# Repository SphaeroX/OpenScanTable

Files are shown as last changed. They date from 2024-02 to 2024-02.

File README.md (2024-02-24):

# OpenScanTable

Welcome to the OpenScanTable project – a modular platform for automated 3D scanning and photography. This project enables users to precisely capture objects from various angles by providing a customizable mount suitable for a wide range of recording devices, including the Revopoint Mini V1 3D scanner and webcams.

## Preview

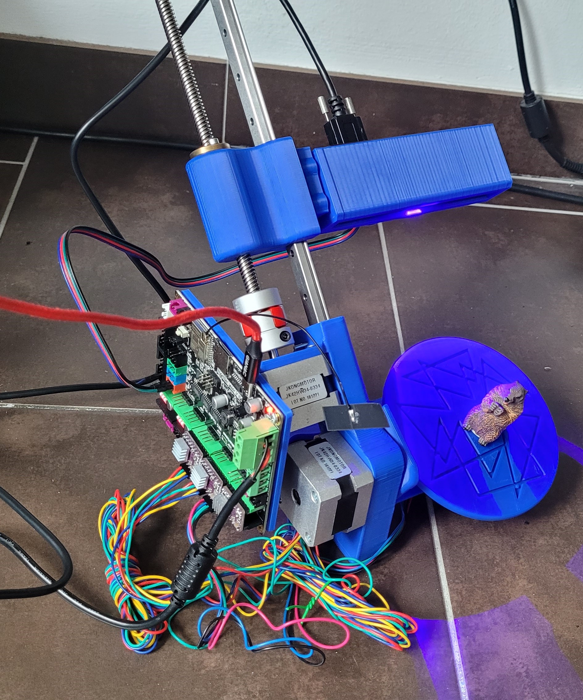
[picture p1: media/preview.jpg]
OpenScanTable in action


[OpenScanTable at YouTube](https://www.youtube.com/shorts/4-4UUVLyI7E "OpenScanTable at YouTube")

## Key Features

- **Modular Design:** Adaptable to different recording devices such as 3D scanners, cameras, and more.
- **Controlled Movements:** Manages the distance, tilt, and rotation of the recording device for optimal results.
- **Automated Scans:** Adjustable scan routines with definable rotation and tilt angles, plus repetitions for complete 360° scans.
- **Bluetooth Control:** Connects to a PC as a Bluetooth device for automated commands, e.g., triggering captures.
- **Web Interface:** Controlled via a user-friendly web interface for easy operation and configuration.
- **3D Printable Components:** All files for 3D printing are available in the hardware folder.

## Technical Details

- **Mainboard:** MKS Tinybee with an ESP32.
- **Programming:** Developed using PlatformIO with the Arduino Library.
- **Automatic Distance Control:** A sensor automatically adjusts the scanner's distance to the object.
- **Versatility:** Suitable for single capture scans with RevoScan or photogrammetry projects with automated image captures.

## Additional Hardware

To assemble OpenScanTable, you will need some additional hardware-
For a complete list of parts and specifications, please refer to the [hardware/BOM.md](./hardware/BOM.md)(Bill of Materials) in this repository.

## Use Cases

- **3D Scanning:** Perfect for detailed 3D models of objects, supported by precise control over capture parameters.
- **Photography:** Ideal for product photography, research and development, where varying perspectives are needed.
- **Photogrammetry:** Enables the creation of 3D models from a series of photographs, including techniques like focus stacking.

## Installation Guide for OpenScanStable

Follow these steps to install and set up your OpenScanStable system. This guide assumes you have a basic understanding of electronics and are familiar with Visual Studio Code and PlatformIO.

First u have to build the hardware (see [hardware/README.md](./hardware/README.md) for more information).

### Pre-requisites

- Visual Studio Code installed on your computer.
- Basic knowledge of using Visual Studio Code and PlatformIO.
- Drivers: https://www.silabs.com/developers/usb-to-uart-bridge-vcp-drivers?tab=downloads
- A MKS TinyBee board or a compatible board.

### Installation Steps

1. **Download and Install PlatformIO Plugin in Visual Studio Code**

   - Open Visual Studio Code.
   - Navigate to the Extensions view by clicking on the square icon on the sidebar or pressing `Ctrl+Shift+X`.
   - Search for "PlatformIO IDE".
   - Click on "Install" to install the PlatformIO IDE extension.

2. **Clone the Repository and Open the Project**

   - Use Git to clone the repository to your local computer. If you're not familiar with Git, you can find numerous guides online to get started.
   - Once cloned, open the folder in Visual Studio Code by selecting `File > Open Folder` and navigating to the cloned project folder.

3. **Prepare and Upload the Firmware to the MKS Tinybee Board**

   - In the PlatformIO sidebar, navigate to the project environment for the MKS Tinybee board.
   - **Build File System Image**
     - First, you need to build the file system image that will be used by the ESP32. This contains the web interface and other necessary files.
     - Find and click on the "Build Filesystem Image" task to compile the image.
   - **Upload File System Image**
     - After building the file system image, upload it to your board by clicking on the "Upload Filesystem Image" task.
   - **Build**
     - Next, compile the main firmware by selecting the "Build" task. This compiles all the source code into a binary file.
   - **Upload**
     - Once the build process is complete, upload the firmware to your MKS Tinybee board by selecting the "Upload" task.

4. **Boot the Mainboard**

   - After uploading the firmware, reboot the MKS Tinybee board to start the newly uploaded software.

5. **Connect Laptop/PC to ESP32 via Bluetooth (For Keyboard Input)**

   - Enable Bluetooth on your laptop or PC.
   - Search for available Bluetooth devices and connect to the ESP32 module named usually as `ESP32 Keyboard`.

6. **Connect to OpenScanStable via WiFi for the Interface**

   - On your computer or a WiFi-enabled device, search for the WiFi network named `OpenScanTable`.
   - Connect to this network using the password provided in your project documentation.
   - Once connected, you can access the web interface by navigating to the IP address specified in the project documentation.

7. **Perform Motor Test and Adjust Drivers**

   - Performing a motor test is essential to confirm that all components are functioning correctly. This step ensures the motors operate as intended for precise control and movement.
   - **Access the Motor Test Feature:** Navigate to the web interface of the OpenScanStable system. Here, you'll find the motor test feature. Follow the on-screen instructions to start the test sequence.
   - **Motor Movement for Distance Measurement:**
     - The motor responsible for moving the measurement device (e.g., sensor) needs to first move upwards before moving downwards. This action ensures that the device can measure the distance accurately and without obstruction.
     - If the motor does not move in the correct order (up then down), you may need to reverse the motor's connection. This adjustment ensures the motor rotates in the correct direction for the intended operation.
   - **Motor Movement for the Rocker:**
     - The motor controlling the rocker (the part that tilts or pivots towards the scanner) should initially rotate towards the scanner. This initial movement is crucial for positioning the object correctly for scanning.
     - If the rocker does not move in the correct direction on the first try, you should reverse the motor's connection. This change will correct the rotation direction, ensuring the rocker moves towards the scanner as intended.
   - **Adjust the Motor Drivers:**
     - During the motor test, carefully adjust the drivers to regulate the amount of current supplied to each motor. The goal is to provide enough current for the motors to operate efficiently without overheating.
     - Supply as much current as necessary for optimal performance but as little as possible to prevent overheating. This balance ensures the longevity and reliability of the motors and drivers.

By following these detailed steps, you can ensure that the motors for the OpenScanStable system are correctly configured and adjusted for optimal performance. This careful setup is crucial for achieving accurate scanning results and maintaining the system's reliability.

## Contributing

The OpenScanTable project thrives on community contribution. We encourage anyone interested to contribute, whether it's through code contributions, creating 3D printing files, or developing new features. Forks and pull requests are warmly welcomed!

## License

This project is open source under an MIT license. For more information, see the LICENSE file.

## Contact

For questions, suggestions, or contributions, please create an issue in the GitHub repository or contact us directly.

We look forward to your contribution and are excited to see what you will create with OpenScanTable!

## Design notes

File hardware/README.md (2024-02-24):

## Pinout

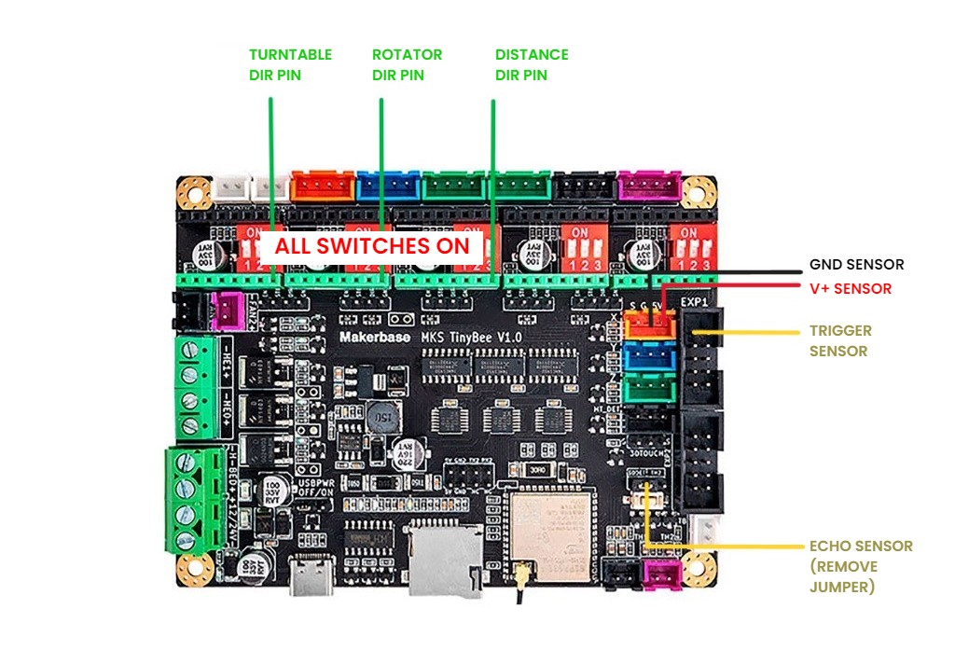
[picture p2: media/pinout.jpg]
Mainboard Pinout


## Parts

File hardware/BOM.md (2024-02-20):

# OpenScanStable - Bill of Materials (BOM)

Below is the Bill of Materials needed to assemble the OpenScanStable project. This list includes 3D-printed parts, electronic components, and other necessary hardware.

## 3D Printed Parts

| Part Name | Quantity | Notes |
| --- | --- | --- |
| Base | 1 | 3D printed |
| Table | 1 | 3D printed |
| Rocker | 1 | 3D printed |
| MGN12_Mount | 1 | 3D printed |
| RP_Mini_Mount | 1 | 3D printed |
| Drive | 1 | 3D printed |
| Mainboard_Mount | 1 | 3D printed |
| Coupler | 1 | 3D printed |

## Electronic Components

| Component | Quantity | Specification |
| --- | --- | --- |
| NEMA 17 Motor | 1 | 42x20mm |
| NEMA 17 Motors | 2 | 42x34mm |
| MKS TinyBee Board | 1 | - |
| Motor Driver (e.g., DRV8825) | 3 | - |
| 24V Power Supply | 1 | 4A |
| VL53L0X Sensor | 1 | - |
| Sensor Cables | - | Preferably with Dupont Connectors |

## Mechanical Components

| Component | Quantity | Specification |
| --- | --- | --- |
| MGN12H Linear Rail | 1 | 250mm Length |
| TR8x8 Lead Screw with T8 Brass Nut | 1 | min 250mm, Acme Thread, 2mm Pitch |
| M3 Screws (20x12mm) | 20 | - |
| M3 Screws (8x10mm) | 10 | - |

Please make sure to source high-quality components to ensure the stability and reliability of your OpenScanStable build. This BOM is provided as a guideline and may be adjusted based on availability or project updates.

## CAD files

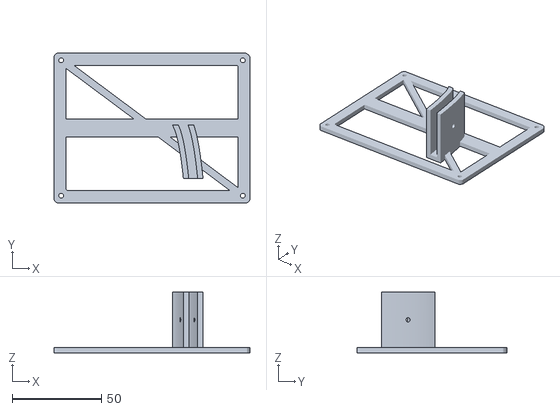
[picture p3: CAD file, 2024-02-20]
hardware/stl/Mainboard_Mount.stl
110.0 x 84.0 x 34.0

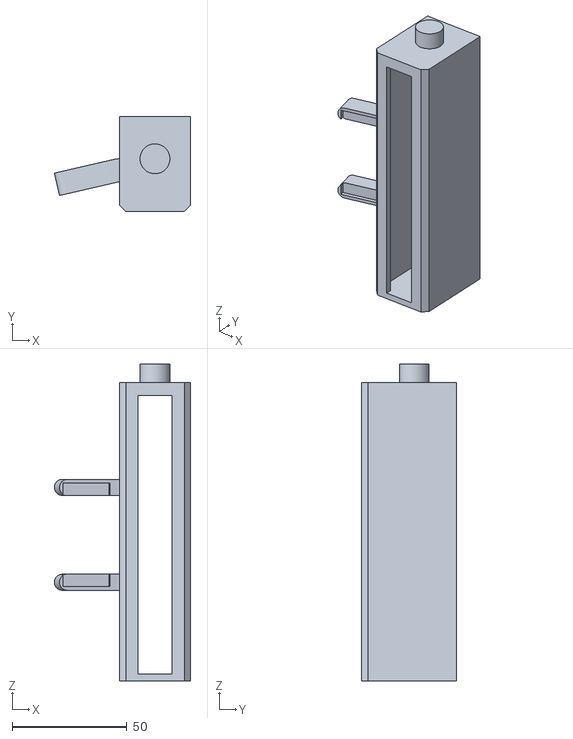
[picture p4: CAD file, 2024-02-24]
hardware/stl/RP_Mini_Mount.stl
59.4 x 41.3 x 138.0

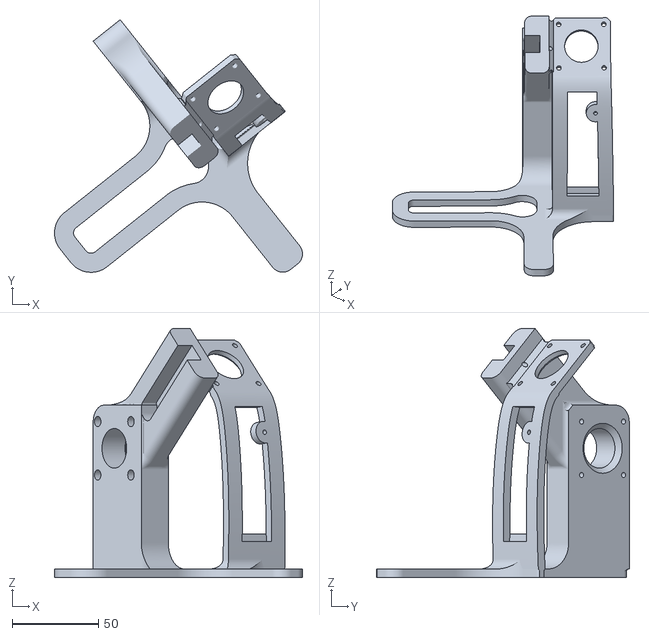
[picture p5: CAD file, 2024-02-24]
hardware/stl/Base.stl
143.9 x 146.6 x 144.5

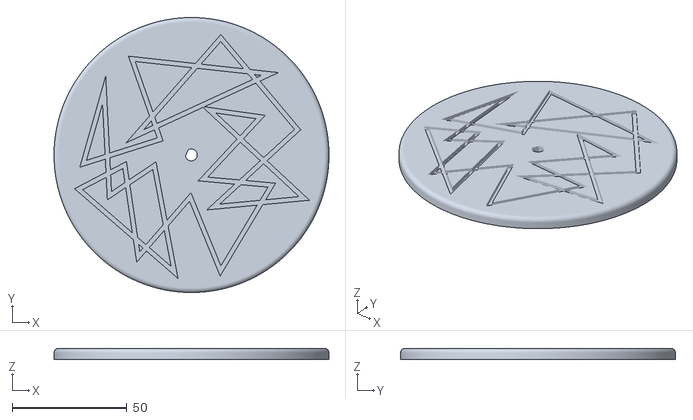
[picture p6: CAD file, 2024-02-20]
hardware/stl/Table.stl
120.0 x 120.0 x 5.00

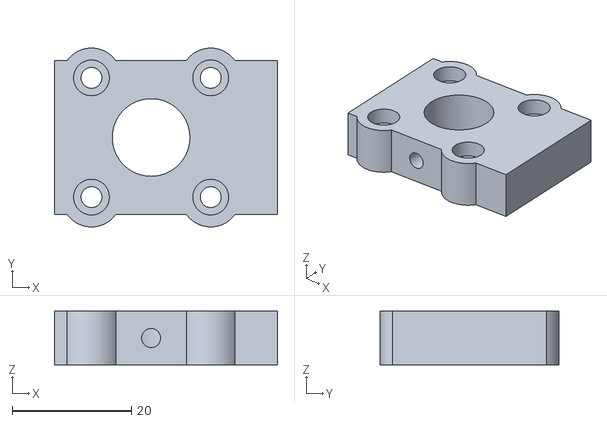
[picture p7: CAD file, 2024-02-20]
hardware/stl/MGN12_Mount.stl
37.4 x 30.0 x 9.00

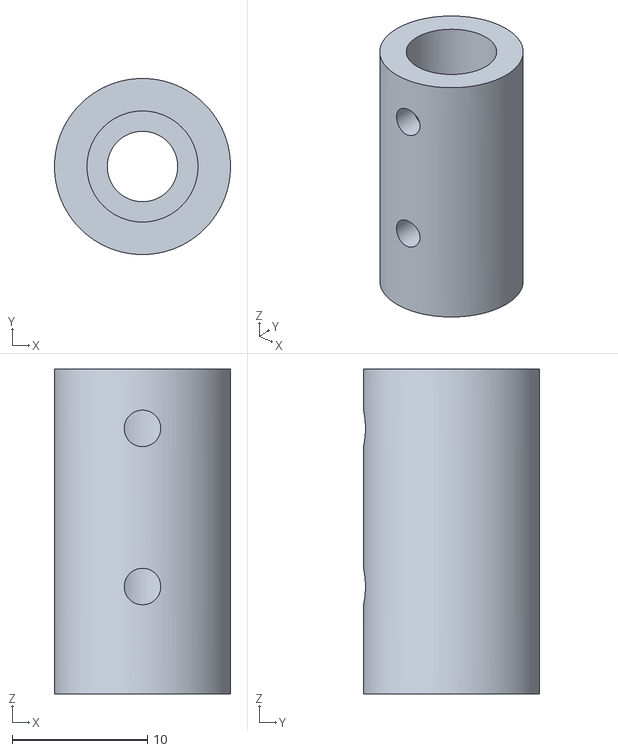
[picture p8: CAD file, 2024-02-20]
hardware/stl/Coupler.stl
13.0 x 13.0 x 24.0

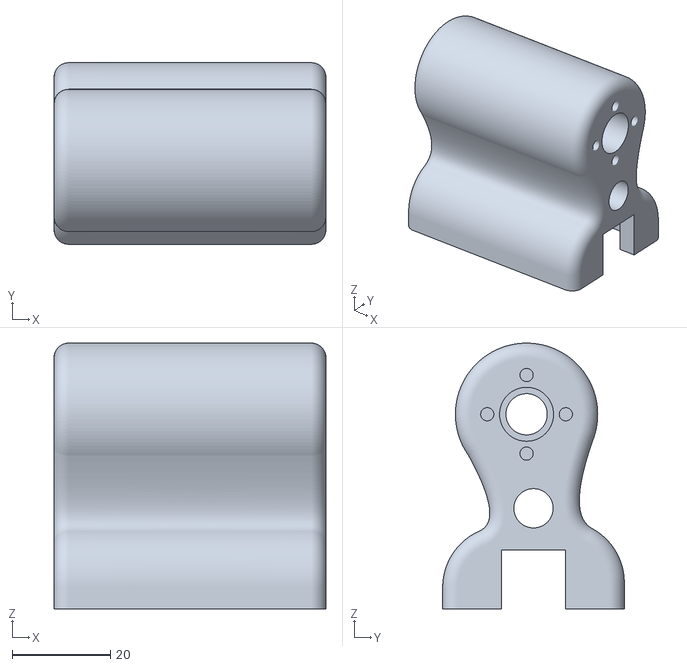
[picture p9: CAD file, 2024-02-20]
hardware/stl/Drive.stl
55.4 x 37.0 x 54.1

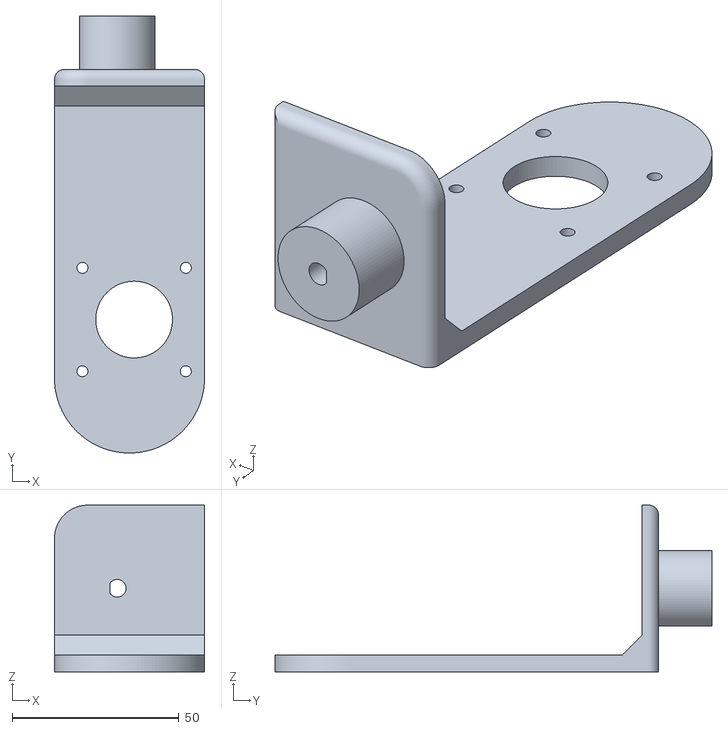
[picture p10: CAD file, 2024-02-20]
hardware/stl/Rocker.stl
45.0 x 131.0 x 50.0

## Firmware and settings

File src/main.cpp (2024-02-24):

#include <Arduino.h>
#include "config.h"
#include "EepromControl.h"
#include "IOExpander.h"
#include "DistanceSensor.h"
#include "MotorControl.h"
#include "BluetoothControl.h"
#include "WebInterface.h"
#include "ScanRoutine.h"

void setup()
{
  Serial.begin(115200);
  setupIOExpander();
  setupMotors();
  setupDistanceSensor();
  setupBluetooth();
  setupWebServer();
  setupEEPROM(512);
  Serial.println("setup");
}

void loop()
{
  loopWebServer();

  switch (commandState)
  {
  case 100:
    Serial.println("SAVE SETTINGS");
    saveSettings();
    commandState = 0;
    break;
  case 200:
    Serial.println("START REVO SCAN IN 5 SECOUNDS");
    delay(5000);
    performRevoScan(zDegrees, zRotations, yDegrees, yRotations, scanShotPause);
    commandState = 0;
    break;
  case 900:
    // todo textaxes zu motor
    Serial.println("Testing X");
    textAxes();
    commandState = 0;
    break;
  case 910:
    Serial.print("Testing Distance: ");
    Serial.println(measureDistance());
    commandState = 0;
    break;
  }
}

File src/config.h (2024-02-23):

// config.h
#ifndef CONFIG_H
#define CONFIG_H

// PIN-Konfigurationen Anschlüsse
#define ULTRASONIC_ECHO 34    // Y -
#define ULTRASONIC_TRIGGER 22 // I2S: BEEPER

// PIN-Konfigurationen Expander
#define EN_PIN_X 1   // X_ENABLE
#define STEP_PIN_X 2 // X_STEP
#define DIR_PIN_X 3  // X_DIR

#define EN_PIN_Y 4   // Y_ENABLE
#define STEP_PIN_Y 5 // Y_STEP
#define DIR_PIN_Y 6  // Y_DIR

#define EN_PIN_Z 7   // Z_ENABLE
#define STEP_PIN_Z 8 // Z_STEP
#define DIR_PIN_Z 9  // Z_DIR

#define ULTRASONIC_TRIG 22 // BEEPER

// I2S-Konfigurationen
#define CLOCK_PIN 25 // I2S_BCK
#define LATCH_PIN 26 // I2S_WS
#define DATA_PIN 27  // I2S_DATA

// Bluetooth-Konfiguration
// const char *BLUETOOTH_NAME = "3DScannerControl";

// Scaneinstellungen

// Motor-Konfiguration
#define STEP_DELAY_X 400 // Z_ENABLE
#define STEP_DELAY_Y 400 // Z_STEP
#define STEP_DELAY_Z 400 // Z_DIR

// Globale Variablen
int commandState = 0;
int measureDistanceTolerance = 5;  // +- mm at this distance an adujst will be made
int measureDistanceMaxChange = 40; // mm at this distance no adjust will be made because of wrong focus
int zDegrees = 20;
int zRotations = 18;
int yDegrees = 18;
int yRotations = 3;
int scanShotPause = 500;
boolean autoAdjust = false;
char revoScanTrigger = ' ';

// Konstanten für die Motorsteuerung
const int stepsPerRevolution = 6400;
const float mmPerRevolution = 20.0;
const int stepsPerMillimeter = stepsPerRevolution / mmPerRevolution;

#endif

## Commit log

2024-02-20 add bom and pprint files
    [Base.stl, Coupler.stl, Drive.stl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]
2024-02-24 hardware changes
    [Base.stl, RP_Mini_Mount.stl]
